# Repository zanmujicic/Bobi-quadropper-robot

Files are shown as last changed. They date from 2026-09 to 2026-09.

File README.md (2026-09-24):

#  BOBI — The Quadropper

<p align="center">
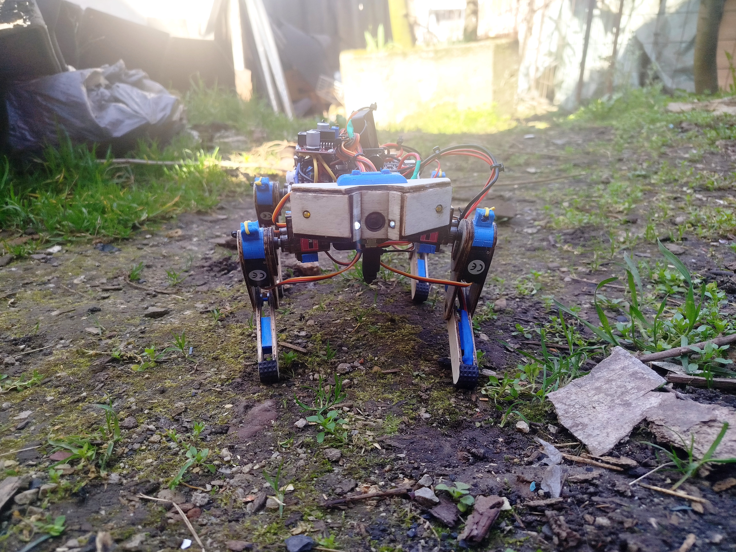
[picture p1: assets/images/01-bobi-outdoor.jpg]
BOBI quadruped robot outdoors
  
</p>

<p align="center">
  <b>An affordable, modular quadruped robot built for robotics education, remote exploration and experimental metal/magnetic detection.</b>
</p>

<p align="center">
  <a href="https://zandomain.dpdns.org/">🌐 Žan Mujičić Portfolio</a> •
  <a href="#overview">Overview</a> •
  <a href="#features">Features</a> •
  <a href="#hardware">Hardware</a> •
  <a href="#testing-results">Testing</a> •
  <a href="#team">Team</a> •
  <a href="#media--documents">Media & Documents</a>
</p>

---

##  Overview

**BOBI — The Quadropper** is a compact quadruped robot developed as a student robotics project at **JU Mješovita srednja industrijska škola in Zenica, Bosnia and Herzegovina**.

The project focuses on building a useful robotic platform with an emphasis on **low cost, modular construction, remote control and practical experimentation**. The prototype combines a lightweight plywood chassis with 3D-printed PLA parts, 12 servo actuators, an ESP32 controller, a camera, lighting and a metal/magnetic detection system.

The project documentation describes intended applications including hazardous-area assistance, exploration of difficult terrain and education.

> **Project type:** Educational / experimental robotics prototype  
> **Controller:** ESP32  
> **Actuation:** 12 servos, 3 DOF per leg  
> **Programming:** C++  
> **Target weight:** ~480 g  
> **Design approach:** Plywood + 3D printing + modular electronics

---

##  Features

-  **Quadruped locomotion** with 3 degrees of freedom per leg
-  **12 servo motors** for leg movement
-  **ESP32** as the main microcontroller
-  Remote operation using an ESP32-based controller
-  Dedicated controller with **9 pushbuttons + joystick**
-  Phone holder for accessing the robot camera
-  **480p mini camera** for remote observation
-  Metal/magnetic detection sensor with visual and audible indication
-  Front white LEDs for low-light environments
-  Yellow side LEDs for signaling
-  Passive buzzer for detection alerts
-  Active cooling with a 30 mm fan and passive heat dissipation
-  Plywood + 3D-printed modular mechanical construction
-  Screw-fastened parts for easier replacement and maintenance
-  Programmed in **C++** for future upgrades

---

##  Mechanical Design

The chassis uses **2.6 mm plywood**, while joints and brackets are made from **PLA 3D-printed parts**. The mechanical components were modeled in CAD before fabrication, and bearings are used at the joints to support smoother movement.

The robot uses a **3-DOF-per-leg architecture**, giving it 12 degrees of freedom in total. This layout provides a useful balance between mobility, mechanical complexity and weight.

The documented prototype weighs approximately **480 g**.

---

##  Hardware

| Component | Specification |
|---|---|
| Main controller | ESP32 |
| Servo driver | PCA9685 PWM module |
| Servos | 8× MG90S + 4× SG90 |
| Degrees of freedom | 12 total / 3 per leg |
| Batteries | 2× 18650 Li-ion |
| Battery protection | Up to 20 A |
| Power conversion | 5 V / 2 A step-down + 5 V / 4 A buck-boost |
| Bearings | 8× MR92-ZZ |
| Detection alert | 12 mm passive buzzer |
| Cooling | 30 mm, 5 V / 0.2 A fan |
| Camera | Mini 480p camera, 5 V / 1 A |
| Frame | 2.6 mm plywood |
| Printed parts | PLA |
| Software | C++ |

The hardware list above follows the project's submitted technical documentation.

---

##  Controller

The custom controller is designed to keep operation simple and accessible.

### Controller hardware

- **ESP32**
- **9 programmable pushbuttons**
- **1 joystick**
- LED indicator for detection
- Phone holder for camera access
- 3D-printed and laser-cut enclosure/components

The project documentation reports a control range of **over 200 m** under its tested/claimed conditions.

---

##  Software & Control

BOBI is programmed in **C++**. The project was designed so that the software can be further optimized and expanded.

The walking tests found that the most stable basic gait was achieved when **three legs remain on the ground while one leg performs the movement**. This provides a stable support triangle during the step cycle.

Possible future software work includes:

- improved gait generation
- better balance and center-of-mass control
- terrain adaptation
- smoother servo trajectories
- autonomous navigation
- sensor fusion
- camera-based remote operation
- additional controller commands

---

##  Testing Results

### Walking stability

| Surface | Stability | Average speed |
|---|---|---:|
| Flat terrain — laminate / tiles | Very stable | **4 cm/s** |
| Concrete | Stable | **3 cm/s** |
| Soil / uneven terrain | Moderately stable | **2.5 cm/s** |

The project documentation also reports:

- Maximum tested descent: **20°**
- Maximum tested ascent: **7.5°**

On uneven terrain, the robot required additional servo correction and moved more slowly, while remaining capable of moving without tipping during the reported tests.

### Metal / magnetic detection experiment

| Distance from sensor | Robot response | Signal |
|---:|---|---|
| **1 cm** | Immediate detection | Strong |
| **1.5 cm** | Detection | Medium |
| **2 cm** | Intermittent detection | Medium → weak |
| **3 cm** | Very rare detection | Very weak |
| **> 4 cm** | No detection | None |

The documented experiment concluded that the sensor performed best at distances up to approximately **2 cm**, with no detection reported beyond 4 cm.

>  **Safety note:** BOBI is an educational/experimental prototype. Its metal/magnetic sensor should **not** be treated as a certified mine-detection or demining system, and the robot must not be used to declare an area safe.

---

##  Project Goals

The project was built around several goals:

1. Develop an affordable quadruped robotic platform.
2. Demonstrate practical robotic locomotion.
3. Explore remote operation of a small mobile robot.
4. Experiment with metal/magnetic anomaly detection.
5. Provide an accessible platform for robotics and programming education.
6. Keep the design modular so damaged parts can be replaced and future upgrades can be added.

The submitted project documentation states an intended total project cost of **under 150 KM** to keep the platform accessible.

---

##  Manufacturing

The project combines several accessible fabrication methods:

**CAD design → 3D printing / laser cutting → mechanical assembly → electronics → programming → testing**

Main fabrication technologies:

-  3D printing for joints, brackets and custom parts
-  Laser cutting for plywood components
-  Plywood for the lightweight structural frame
-  Screws and bearings for serviceable mechanical joints
-  C++ firmware for the control system

---

##  Future Development

BOBI's modular design leaves room for substantial upgrades:

- IMU-based stabilization
- automatic balance correction
- improved inverse-kinematics control
- autonomous walking
- better terrain adaptation
- longer-range communication
- improved camera system
- additional environmental sensors
- improved detection electronics
- redesigned lightweight chassis
- custom PCB integration
- more advanced remote-control software

---

##  More Projects & Information

BOBI is part of a wider collection of robotics, electronics, 3D-printing, CNC, self-hosting and DIY projects.

**More projects, achievements and technical information:**

➡️ **https://zandomain.dpdns.org/**

The portfolio includes additional work such as:
- Robotics and ESP32 projects
- 3D printing and OctoPrint
- CNC laser work
- Custom PCs and electronics
- Home-server and networking projects
- Other technical and DIY projects

**School:** JU Mješovita srednja industrijska škola  
**Location:** Zenica, Bosnia and Herzegovina

The team and school information is taken from the submitted project documents.

---

##  Repository Structure

```text
BOBI-THE-QUADROPPER/
├── README.md
├── assets/
│   ├── images/
│   │   └── 01-bobi-outdoor.jpg
├── docs/
│   ├── BOBI-The-Quadroper-Presentation.pptx
│   └── BOBI-The-Quadroper-Project-Paper.docx
├── code/
```

---

##  References

The submitted project documentation references:

- BHMAC — Bosnia and Herzegovina Mine Action Centre
- Boston Dynamics — Spot
- Arduino
- Autodesk Fusion
- Ultimaker Cura
- Craftseek
- Reddit
- Temu

See the original presentation and project paper in `docs/` for the project's cited bibliography.

---

##  Project Context

BOBI was prepared for the **SCI&TECH Challenge** project context at the University of Zenica / Faculty of Engineering and Natural Sciences where he won first place.

The submitted presentation identifies the project as **SCI&TECH CHALLENGE 2026** and the team as students of JU Mješovita srednja industrijska škola in Zenica.

---

##  License

This project is licensed under MIT licence.

---

<p align="center">
  <b>BOBI — The Quadropper</b><br>
  Student Robotics • ESP32 • 3D Printing • CAD • Electronics • Embedded C++
</p>

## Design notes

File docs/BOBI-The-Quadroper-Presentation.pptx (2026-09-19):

## Bobi the quadropper

Članovi tima:
- Žan Mujičić
- Amna Kolić
- Mirza Čoloman
- Adin Kadrić
Mentor tima: Edina Hodžić
Naziv škole: Mješovita srednja industrijska škola
Mjesto škole: Zenica

SCI&TECH CHALLENGE 2026

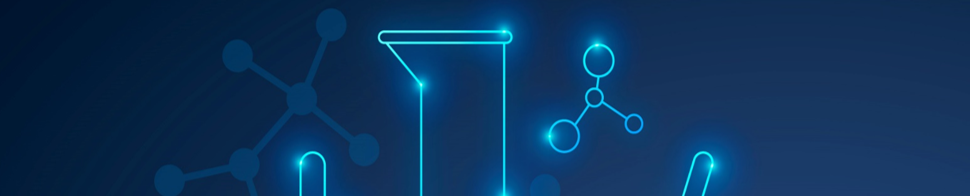
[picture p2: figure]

SCI&TECH CHALLENGE 2026
UNIVERZITET U ZENICI
Fakultet inženjerstva i prirodnih nauka

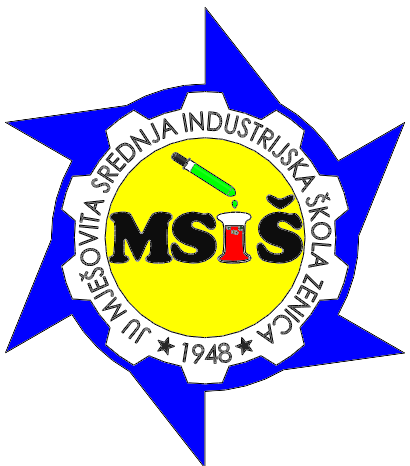
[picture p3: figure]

## Uvod

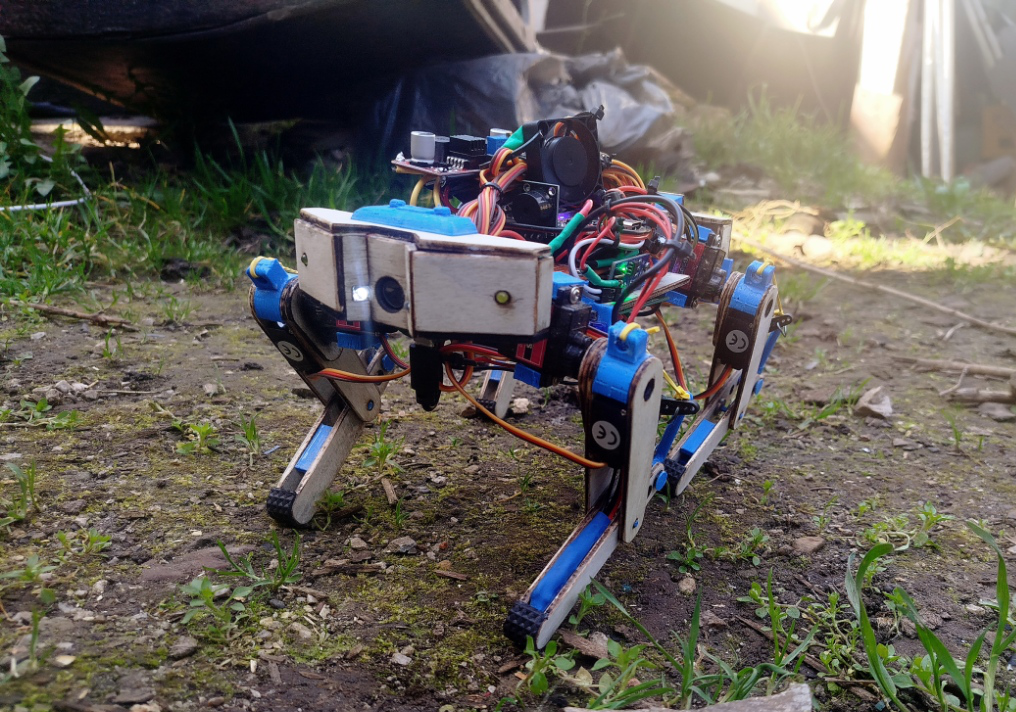
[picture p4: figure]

Slika 1. Robot Bobi u prirodnom okruženju

- Za cilj smo imali da napravimo multifunkcionalnog robotskog psa.
- Njegova funkcionalnost se ogleda u detekciji mina ali i u istraživanju nepristupačnih područja te u ekukaciji zbog svoje open-source platforme.

## Uvod

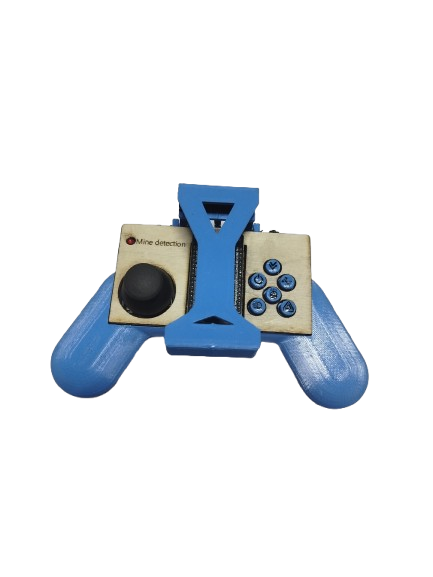
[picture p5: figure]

Slika 2. Izgled kontrolera sa dodatkom za mobilni telefon

- Što se tiče glavnog cilja, detekcija mina, uloga mu je da pomogne u pregledu još neispitanog podrucija oko domaćinstava kojih ima 264,011.
- Kontroler sa jednostavnim dizajnom, držačem za telefon i dometom od preko 200m omogućuje lagano upravljanje na daljinu bez potrebe za posebnom edukacijom.

## Eksperimentalni dio - Općenito

- Izradjen je od šperploče, Slika 3., u kombinaciji sa 3D printanim dijelovima, Slika 4. i 5., radi održavanja optimalne težine od 480g i stabilnog centra mase.
- Od softverskog dijela je potpuno programiran u C++ te su daljnje optimizacije i nadogradnje jednostavne za instalaciju.
Slike 3,4,5. Proces izrade dijelova za kontroler

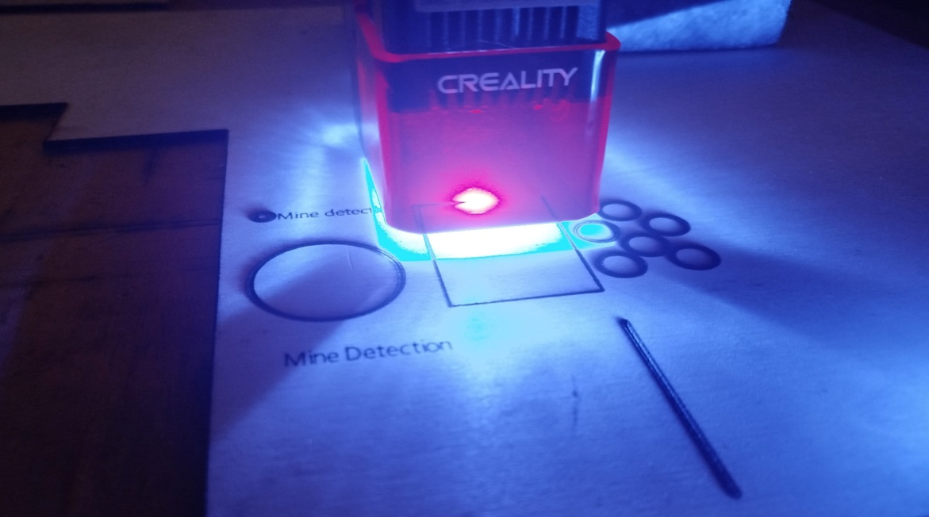
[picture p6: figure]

Slika 3.
Slika 4. Slika 5.

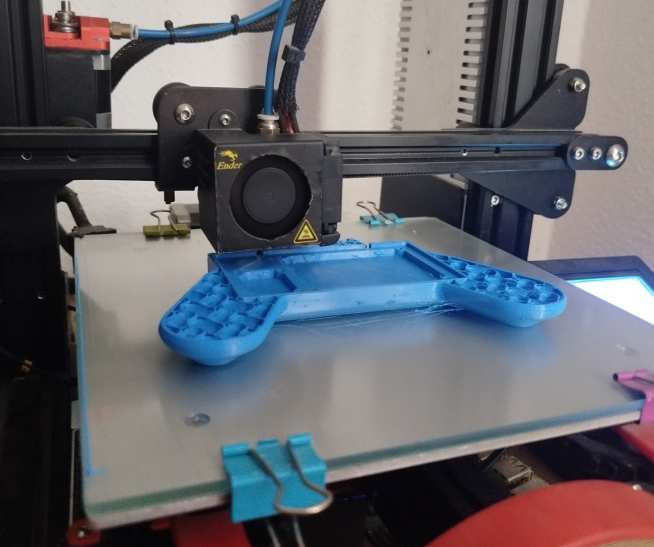
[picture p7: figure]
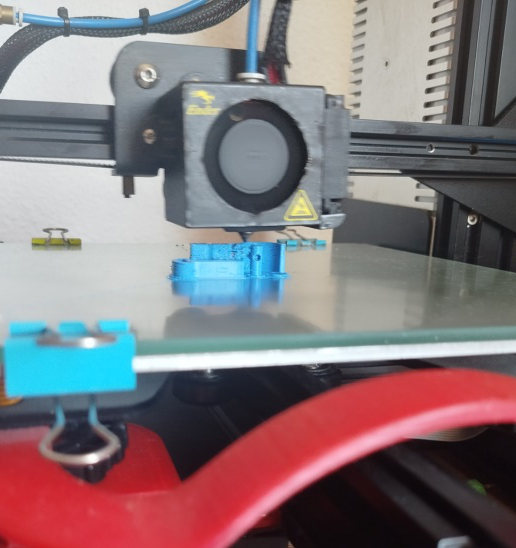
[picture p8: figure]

## Eksperimentalni dio – Robotski pas

- Pokreće ga ESP32, Slika 6., te je opremljen sa 12 servo motora, Slika 8. i 9, što mu daje 3 stepena slobode po nozi.
- Za područja sa slabim osvijetljenjem posjeduje dvije bijele led diode na prednjoj strani i po dvije žute led diode na svakoj strani.
- Aktivni i pasivni hladnjaci osiguravaju kontinuiran rad bez pregrijavanja.

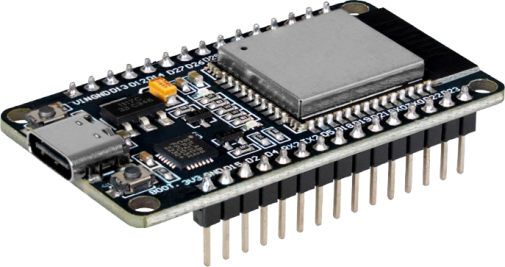
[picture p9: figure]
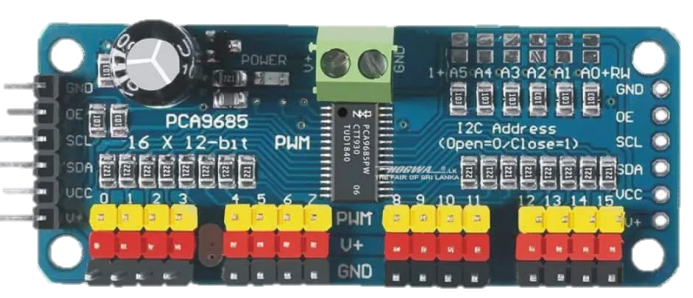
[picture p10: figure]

Slika 6. ESP32 Slika 7. PCA9685
Slika 8. MG90S Slika 9. SG90

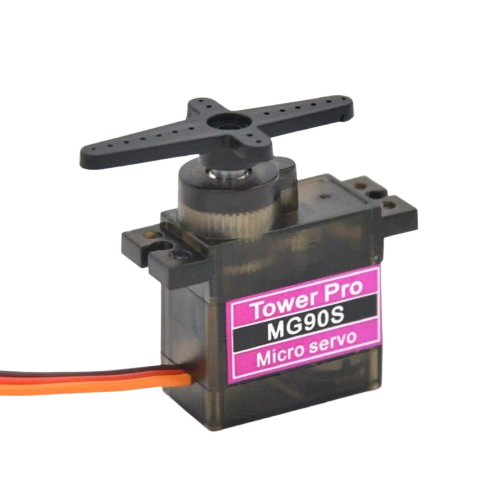
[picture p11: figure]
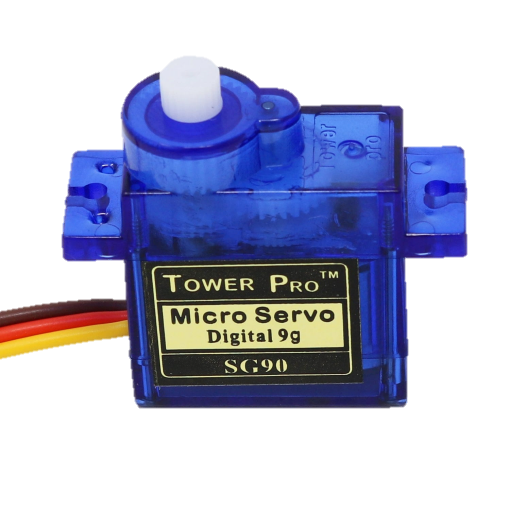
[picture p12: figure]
TowerPro Servo Motor - SG90 Digital - The Pi Hut

## Eksperimentalni dio - Kontroler

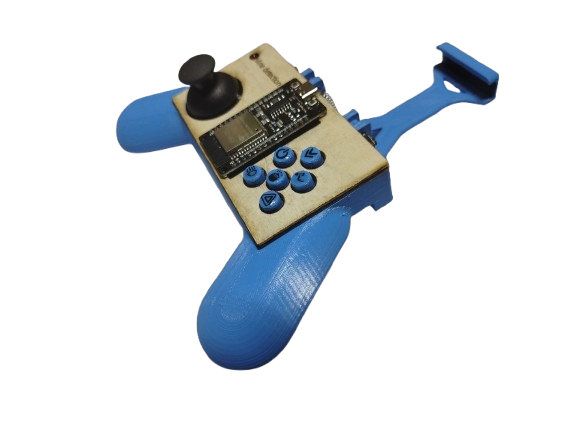
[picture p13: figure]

9x Pushbutton tipki
1x Joystic
3D printanje i Lasersko rezanje

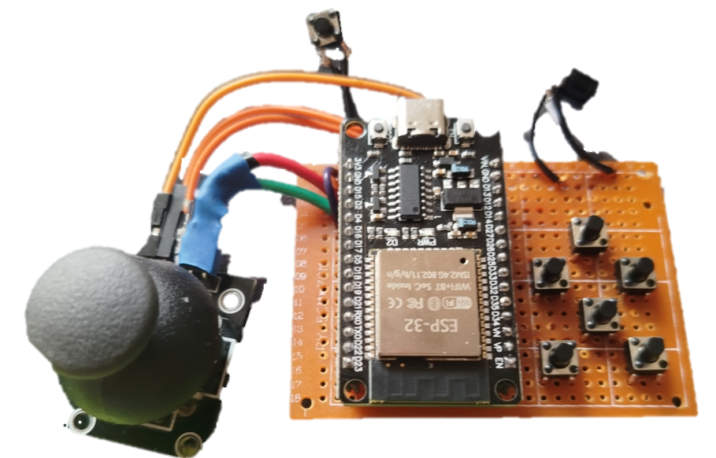
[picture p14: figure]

Slika 11. Završni izgled kontrolera

Led indikator detekcije mina
Držač telefona za pristup kameri
Pogonjen sa ESP32

Slika 10. Matična ploča kontrolera

## Rezultati ispitivanja/Analiza rezultata

- Kod hodanja zaključili smo da je najstabilniji način kretanja kad su mu tri noge uvijek na tlu dok jedna obavlja kretnju.
- Pri detekciji mine aktivira se buzer koji počinje da daje zvučni signal za detekciju kao i aktivacija žutih led dioda za signalizaciju.

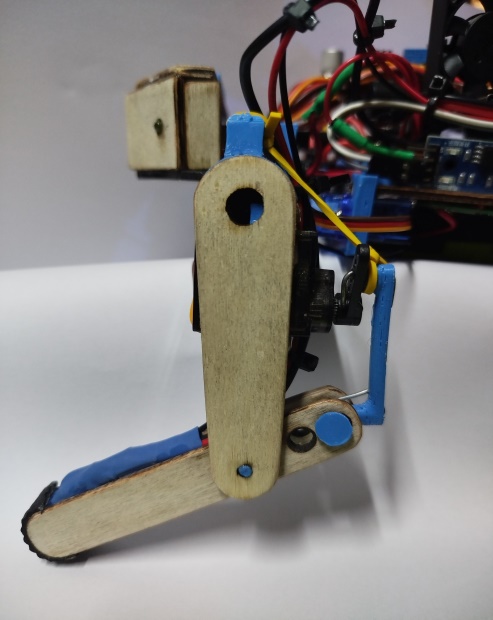
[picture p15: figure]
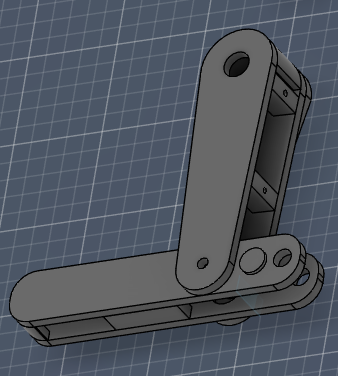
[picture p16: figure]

Slika 12. Dizajn noge u stvarnosti i u CAD softveru

## Rezultati ispitivanja/Analiza rezultata

## Zaključci

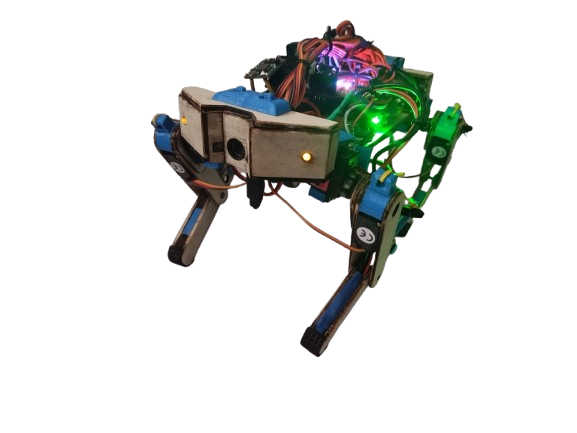
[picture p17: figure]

Slika 13. Robot pas „Bobi”

- Naš robot je izređen sa ciljem da pomogne u poslovima koji nisu sigurni i pristupačni za ljude ali i za edukaciju u smislu programiranja.
- Pri izradi i odabiru dijelova smo išli na to da sveukupna cijena ne prelazi 150KM kako bi bio što pristupačniji običnim korisnicima.

## Zaključci

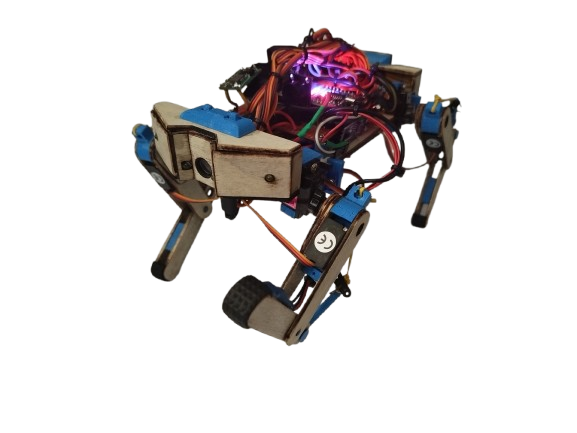
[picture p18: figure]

- Samo upravljanje robotom je napravljno što jednostavnije da bi njime mogao bilo ko upravljati ali je programiran na način da radi samo sa ranije navedenim kontrolerom.
- Radi tri stepena slobode po nozi mogući su mu razni specijalni pokreti i kretnje poput mahanja ili čak plesanja.

## Literatura

- [1] https://www.bhmac.org/ (12.09.2025.)
- [2] https://bostondynamics.com/products/spot/ (19.09.2025.)
- [3] https://www.arduino.cc/en/software/ (17.09.2025.)
- [4] https://www.autodesk.com/products/fusion-360/overview (04.09.2025.)
- [5] https://ultimaker.com/software/ultimaker-cura/ (15.09.2025.)
- [6] https://webapp.craftseek.com/#/download (24.09.2025.)

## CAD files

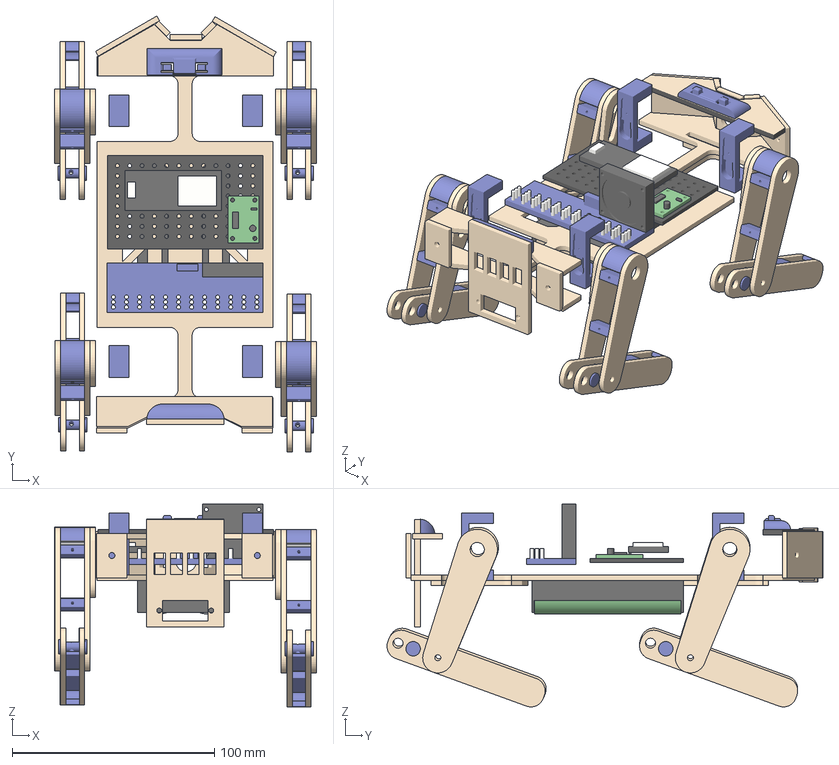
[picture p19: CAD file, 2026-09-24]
models/robo_dog_assembled.3mf
129.7 x 215.8 x 100.4 mm

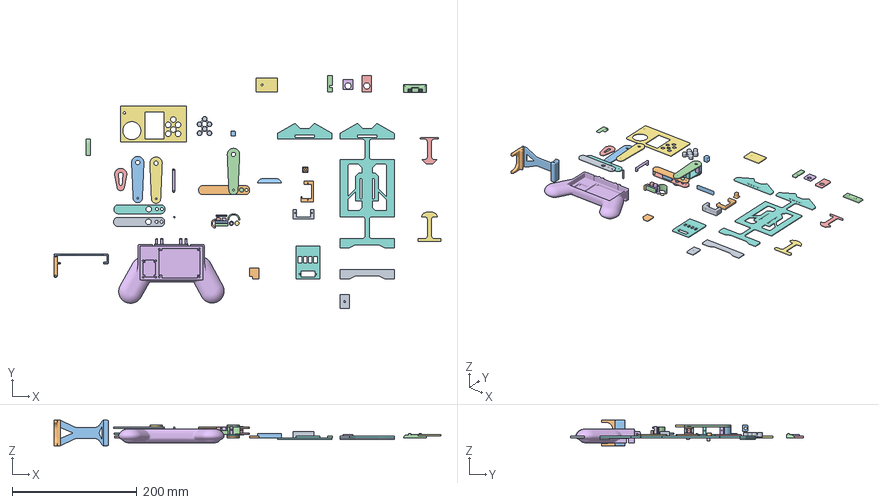
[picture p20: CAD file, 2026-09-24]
models/robo_dog_parts.3mf
620.9 x 373.5 x 41.3 mm

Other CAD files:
models/robo_dog_assembled.f3d
models/robo_dog_parts.f3d

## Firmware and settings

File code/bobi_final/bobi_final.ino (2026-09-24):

#include <Wire.h>
#include <Adafruit_PWMServoDriver.h>
#include <esp_now.h>
#include <WiFi.h>

#define I2C_SDA_PIN 21
#define I2C_SCL_PIN 22
#define SERVOMIN  170
#define SERVOMAX  490
bool state13 = false; // Prati stanje pina 13 
bool state12 = false; // Prati stanje pina 12
Adafruit_PWMServoDriver pwm = Adafruit_PWMServoDriver(0x40);
char receivedChar = 'S';
int senz = 0;

typedef struct struct_message {
    char command;
} struct_message;
struct_message incomingData;

void setServoAngle(uint8_t channel, int angle) {
  if (angle < 0) angle = 0;
  if (angle > 180) angle = 180;
  int pulse = map(angle, 0, 180, SERVOMIN, SERVOMAX);
  pwm.setPWM(channel, 0, pulse);
}

void SSS() {
  setServoAngle(0, 90); setServoAngle(1, 90); setServoAngle(2, 90); setServoAngle(3, 80);
  delay(50);
  setServoAngle(4, 110); setServoAngle(6, 150); setServoAngle(7, 30); setServoAngle(5, 60);
  delay(50);
  setServoAngle(8, 70); setServoAngle(9, 140); setServoAngle(10, 40); setServoAngle(11, 150);
}

void OnDataRecv(const uint8_t * mac, const uint8_t *incomingDataRaw, int len) {
  memcpy(&incomingData, incomingDataRaw, sizeof(incomingData));
  receivedChar = incomingData.command;
}

void setup() {
  Serial.begin(115200);
  WiFi.mode(WIFI_STA); // Obavezno za ESP-NOW [cite: 1, 111]
  
  pinMode(2, OUTPUT); 
  pinMode(25, OUTPUT); 
  pinMode(27, INPUT); // Senzor pin [cite: 9, 107]
  pinMode(12, OUTPUT);
  pinMode(13, OUTPUT);
  digitalWrite(13, LOW);
  digitalWrite(12, HIGH);
  delay(1000);
  digitalWrite(12, LOW);

  
  if (esp_now_init() != ESP_OK) {
    Serial.println("ESP-NOW Init Failed");
    return;
  }
  
  // Registracija callback-a
  esp_now_register_recv_cb(esp_now_recv_cb_t(OnDataRecv));

  Wire.begin(I2C_SDA_PIN, I2C_SCL_PIN); // I2C za PWM driver [cite: 1, 10]
  pwm.begin();
  pwm.setPWMFreq(50); // Servo frekvencija [cite: 10]
  SSS(); // Postavi u početnu pozu [cite: 2, 11]
}

void loop() {
  digitalWrite(2, !digitalRead(27));
  if (digitalRead(27) == LOW && senz == 1) {
    digitalWrite(12, HIGH); tone(25, 1000); delay(100); noTone(25); delay(100);
  }

  switch (receivedChar) {
    case 'F': 

 setServoAngle(0, 90); setServoAngle(1, 90); setServoAngle(2, 90); setServoAngle(3, 80);
  delay(100);
  setServoAngle(4, 140); setServoAngle(6, 180); setServoAngle(7, 20); setServoAngle(5, 40);
  delay(100);
  setServoAngle(8, 70); setServoAngle(9, 140); setServoAngle(10, 40); setServoAngle(11, 150);

    
  // ===== FAZA 1: zadnja lijeva =====
  setServoAngle(1, 105); 
  setServoAngle(2, 80);  
  delay(80);

  setServoAngle(10, 125); 
  delay(80);

  setServoAngle(6, 150);  
  delay(100);

  setServoAngle(10, 45);  
  delay(100);

  // ===== FAZA 2: prednja desna =====
  setServoAngle(0, 80); 
  setServoAngle(3, 100);
  delay(80);

  setServoAngle(9, 80);  
  delay(80);

  setServoAngle(5,70);  
  delay(100);

  setServoAngle(9, 140); 
  delay(100);

  // ===== FAZA 3: zadnja desna =====
  setServoAngle(0, 85); 
  setServoAngle(3, 95);
  delay(80);

  setServoAngle(11, 50); 
  delay(110);

  setServoAngle(7, 40);  
  delay(100);

  setServoAngle(11, 180);
  delay(120);

  // ===== FAZA 4: prednja lijeva =====
  setServoAngle(1, 100); 
  setServoAngle(2, 85);
  delay(80);

  setServoAngle(8, 145); 
  delay(80);

  setServoAngle(4, 110);  
  delay(100);

  setServoAngle(8, 80);  
  delay(100);

  // ===== POVRATAK =====
  setServoAngle(0, 90);
  setServoAngle(1, 90);
  setServoAngle(2, 90);
  setServoAngle(3, 80);

  delay(150);
  SSS();
      break;

    case 'B': 
 // ===== POČETNA STABILIZACIJA =====
setServoAngle(0, 90); 
setServoAngle(1, 90);
setServoAngle(2, 90);
setServoAngle(3, 70);
delay(60);

// ===== FAZA A (FL + BR) =====

// 1. SHIFT TEŽINE (max 2 serva)
setServoAngle(0, 80);
setServoAngle(3, 85);
delay(80);

// 2. PODIGNI FL (2 serva max)
setServoAngle(8, 150);   // FL gore
delay(70);

// 3. POMAKNI FL NAPRIJED (1 servo)
setServoAngle(4, 140);
delay(80);

// 4. SPUSTI FL
setServoAngle(8, 70);
delay(70);

// 5. PODIGNI BR (2 serva max)
setServoAngle(11, 60);
delay(70);

// 6. POMAKNI BR NAPRIJED
setServoAngle(7, 20);
delay(80);

// 7. SPUSTI BR
setServoAngle(11, 140);
delay(80);

// ===== GURANJE TIJELA =====
setServoAngle(4, 110);
setServoAngle(7, 20);
delay(100);


// ===== FAZA B (FR + BL) =====

// 1. SHIFT TEŽINE
setServoAngle(1, 100);
setServoAngle(2, 80);
delay(80);

// 2. PODIGNI FR
setServoAngle(9, 50);
delay(70);

// 3. POMAKNI FR
setServoAngle(5, 40);
delay(80);

// 4. SPUSTI FR
setServoAngle(9, 140);
delay(70);

// 5. PODIGNI BL
setServoAngle(10, 130);
delay(70);

// 6. POMAKNI BL
setServoAngle(6, 180);
delay(80);

// 7. SPUSTI BL
setServoAngle(10, 50);
delay(80);

// ===== GURANJE TIJELA =====
setServoAngle(5, 60);
setServoAngle(6, 160);
delay(100);


// ===== POVRATAK CENTAR =====
setServoAngle(0, 90);
setServoAngle(1, 90);
delay(60);
setServoAngle(2, 90);
setServoAngle(3, 70);
delay(60);


      break;

    case 'L': 
          // ================== FAZA A ==================
// podigni prednju lijevu i zadnju desnu
setServoAngle(8, 130);
setServoAngle(11, 70);
delay(80);

// pomjeri naprijed i blago u lijevo
setServoAngle(4, 150);  // p lijeva
setServoAngle(7, 25);   // z desna
delay(160);

// spusti noge
setServoAngle(8, 80);
setServoAngle(11, 100);
delay(120);

// lagano guranje tijela
setServoAngle(0, 85);   
setServoAngle(3, 95);
delay(100);

// ================== FAZA B ==================
// podigni prednju desnu i zadnju lijevu
setServoAngle(9, 60);
setServoAngle(10, 120);
delay(80);

// pomjeri naprijed i blago u lijevo
setServoAngle(5, 65);   // p desna
setServoAngle(6, 180);  // z lijeva
delay(160);

// spusti noge
setServoAngle(9, 90);
setServoAngle(10, 70);
delay(120);

// guranje tijela
setServoAngle(1, 95);
setServoAngle(2, 85);
delay(100);

// povratak u neutralu
setServoAngle(4, 125);
setServoAngle(5, 30);
setServoAngle(6, 155);
setServoAngle(7, 15);
delay(200);
         SSS();
           
        
      break;

    case 'R': 
         // ================== FAZA A ==================
// podigni prednju desnu i zadnju lijevu
setServoAngle(9, 70);
setServoAngle(10, 120);
delay(100);

// pomjeri naprijed i blago u desno
setServoAngle(5, 55);   // p desna
setServoAngle(6, 165);  // z lijeva
delay(160);

// spusti noge
setServoAngle(9, 90);
setServoAngle(10, 70);
delay(120);

// lagano guranje tijela
setServoAngle(1, 95);
setServoAngle(2, 85);
delay(120);

// ================== FAZA B ==================
// podigni prednju lijevu i zadnju desnu
setServoAngle(8, 130);
setServoAngle(11, 70);
delay(110);

// pomjeri naprijed i blago u desno
setServoAngle(4, 125);  // p lijeva
setServoAngle(7, 15);   // z desna
delay(160);

// spusti noge
setServoAngle(8, 80);
setServoAngle(11, 100);
delay(120);

// guranje tijela
setServoAngle(0, 85);   
setServoAngle(3, 95);
delay(110);

// povratak u neutralu
setServoAngle(4, 150);
setServoAngle(5, 25);
setServoAngle(6, 180);
setServoAngle(7, 30);
delay(200);
       
         
      break;

    case 'a': 
       
  // ===== POČETNA POZA =====
  setServoAngle(0, 90); setServoAngle(1, 90);
  setServoAngle(2, 90); setServoAngle(3, 90);
   delay(60);
  setServoAngle(4, 110); setServoAngle(5, 60);
  setServoAngle(6, 150); setServoAngle(7, 30);
   delay(60);
  setServoAngle(8, 70); setServoAngle(9, 140);
  delay(100);
  setServoAngle(10, 40); setServoAngle(11, 150);
  delay(400);
  SSS();

  // ===== DANCE 1: BODY SWAY L-R =====
  for (int i = 0; i < 2; i++) {
    // lijevo
    setServoAngle(0, 70); setServoAngle(1, 70); delay(90);
    setServoAngle(2, 110); setServoAngle(3, 110);
       
    delay(450);



    // desno
    setServoAngle(0, 110); setServoAngle(1, 110); delay(90);
    setServoAngle(2, 70); setServoAngle(3, 70);
      
    delay(450);
  }

  // ===== DANCE 2: FRONT PAW TAP =====
  // prednja lijeva
  setServoAngle(8, 160); delay(270);
  setServoAngle(4, 120); delay(250);
  setServoAngle(8, 90);  delay(290);
   
  // prednja desna
  setServoAngle(9, 40);  delay(250);
  setServoAngle(5, 50);  delay(270);
  setServoAngle(9, 120); delay(290);

  // ===== DANCE 3: BACK KICK =====
  // zadnja lijeva
  setServoAngle(10, 130); delay(250);
  setServoAngle(6, 160);  delay(250);
  setServoAngle(10, 40);  delay(290);

  // zadnja desna
  setServoAngle(11, 50); delay(220);
  setServoAngle(7, 20);   delay(220);
  setServoAngle(11, 150);delay(290);
     
  // ===== DANCE 4: BOUNCE (čučanj) =====
  for (int i = 0; i < 2; i++) {
    setServoAngle(8, 20); setServoAngle(9, 160);
   
    
    delay(420);

    setServoAngle(8, 90); setServoAngle(9, 90);
    
    
    delay(420);
  }

  SSS();




for (int i = 0; i < 2; i++) {
    // lijevo
    setServoAngle(0, 70); setServoAngle(1, 70);
    
    delay(450);

    // desno
    setServoAngle(0, 110); setServoAngle(1, 110);
  
    delay(470);
  }
  // ===== POVRATAK U STOJ =====
  setServoAngle(8, 180);   //spusta kod lakta
         setServoAngle(9, 0);
         delay(150);
         setServoAngle(10, 10);
         setServoAngle(11, 170);
         delay(150);

         setServoAngle(4, 110);   //vraca na pocetak

         setServoAngle(5, 75);   //vraca na pocetak
        delay(600);   
  SSS();
delay(450);

    // ===== DANCE 1: BODY SWAY L-R =====
  for (int i = 0; i < 3; i++) {
    // lijevo
    setServoAngle(0, 70); setServoAngle(1, 70);
    delay(60);
    setServoAngle(2, 110); setServoAngle(3, 110);
    delay(450);

    // desno
    setServoAngle(0, 110); setServoAngle(1, 110);
    delay(60);
    setServoAngle(2, 70); setServoAngle(3, 70);
    delay(450);
  }

 SSS();

  // ===== POVRATAK U STOJ =====
  setServoAngle(8, 180);   //spusta kod lakta
         setServoAngle(9, 0);
         delay(100);
         setServoAngle(10, 10);
         delay(60);
         setServoAngle(11, 170);
         delay(100);

         setServoAngle(4, 120);   //vraca na pocetak
         delay(60);
         setServoAngle(5, 50);   //vraca na pocetak
        delay(600);   
  SSS();
 


      break;

    case 'A': 
      setServoAngle(8, 0); setServoAngle(9, 170);  setServoAngle(10, 10); delay(200);
       setServoAngle(8, 180); setServoAngle(1, 105); setServoAngle(6, 155); delay(40); setServoAngle(4, 10); delay(510);
      for(int j=0; j<3; j++) { setServoAngle(8, 130); delay(400); setServoAngle(8, 180); delay(400); }
      
      break;



       case 'X': 
       setServoAngle(0, 120);  
         setServoAngle(1, 120); 
         delay(60); 
         setServoAngle(2, 120);  
         setServoAngle(3, 110);  
      
      break;




       case 'Y': 
        setServoAngle(0, 55);  
         setServoAngle(1, 55);  
         delay(50);
         setServoAngle(2, 55);  
         setServoAngle(3, 55);  
      
      break;




    case 'S': SSS(); break;
    case 'D': 
        setServoAngle(8, 180);   //spusta kod lakta
         setServoAngle(9, 0);
         delay(100);
         setServoAngle(10, 10);
         setServoAngle(11, 170);
         delay(100);

         setServoAngle(4, 120);   //vraca na pocetak

         setServoAngle(5, 50);   //vraca na pocetak
    
    ; break;
    case '1': senz=1;break;
    case '0': senz = 0; 
    digitalWrite(12, LOW);
    digitalWrite(13, LOW);
    
    break;
    case 'Q': digitalWrite(13, HIGH); break;
    case 'T': digitalWrite(12, HIGH); break;
    

    
  }
}

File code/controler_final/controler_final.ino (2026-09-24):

#include <esp_now.h>
#include <WiFi.h>

// MAC adresa tvog psa
uint8_t broadcastAddress[] = {0x80, 0xF3, 0xDA, 0x62, 0x88, 0xF4};

typedef struct struct_message {
    char command;
} struct_message;

struct_message myData;
esp_now_peer_info_t peerInfo;
bool lastState13 = HIGH;
bool lastState12 = HIGH;
// Pinovi kontrolera
#define JOY_X 34
#define JOY_Y 35
#define BTN_SIT 13      // Komanda 'S'
#define BTN_DANCE 12    // Komanda 'a'
#define BTN_ATTACK 14   // Komanda 'A'
#define BTN_GYRO_OFF 27 // Komanda '0'
#define BTN_GYRO_ON 26  // Komanda '1'
#define BTN_LIGHT_13 33
#define BTN_LIGHT_12 17
#define BTN_NL_25 25
#define BTN_NR_2 15

#define BTN_L13 BTN_LIGHT_13
#define BTN_L12 BTN_LIGHT_12
void setup() {
  Serial.begin(115200);
  WiFi.mode(WIFI_STA);

  if (esp_now_init() != ESP_OK) return;

  memcpy(peerInfo.peer_addr, broadcastAddress, 6);
  peerInfo.channel = 0;  
  peerInfo.encrypt = false;
  
  if (esp_now_add_peer(&peerInfo) != ESP_OK) return;

  pinMode(BTN_SIT, INPUT_PULLUP);
  pinMode(BTN_DANCE, INPUT_PULLUP);
  pinMode(BTN_ATTACK, INPUT_PULLUP);
  pinMode(BTN_GYRO_OFF, INPUT_PULLUP);
  pinMode(BTN_GYRO_ON, INPUT_PULLUP);
  pinMode(BTN_LIGHT_12, INPUT_PULLUP);
  pinMode(BTN_LIGHT_13, INPUT_PULLUP);
  pinMode(BTN_NL_25, INPUT_PULLUP);
  pinMode(4, OUTPUT);
}

void loop() {
  int xVal = analogRead(JOY_X);
  int yVal = analogRead(JOY_Y);
  char cmd = 'S'; 

  // Logika džojstika
  if (yVal < 1000) cmd = 'F';      
  else if (yVal > 3000) cmd = 'B'; 
  else if (xVal < 1000) cmd = 'R'; 
  else if (xVal > 3000) cmd = 'L'; 
   else if (digitalRead(BTN_NL_25) == LOW) cmd = 'X';
  else if (digitalRead(BTN_NR_2) == LOW) cmd = 'Y';
  // Logika dugmadi
  else if (digitalRead(BTN_SIT) == LOW) cmd = 'D';      
  else if (digitalRead(BTN_DANCE) == LOW) cmd = 'a';    
  else if (digitalRead(BTN_ATTACK) == LOW) cmd = 'A';   
  else if (digitalRead(BTN_GYRO_ON) == LOW) {cmd = '1';  digitalWrite(4, HIGH);}  
  else if (digitalRead(BTN_GYRO_OFF) == LOW) {cmd = '0';  digitalWrite(4, LOW); }
  else if (digitalRead(BTN_LIGHT_12) == LOW) cmd = 'T';  
  else if (digitalRead(BTN_LIGHT_13) == LOW) cmd = 'Q'; 
 



  myData.command = cmd;
  esp_now_send(broadcastAddress, (uint8_t *) &myData, sizeof(myData));
  delay(100); 
}
